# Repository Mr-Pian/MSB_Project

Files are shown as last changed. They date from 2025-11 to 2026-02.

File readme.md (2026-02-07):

# 2025 盟升杯电子设计竞赛 - G题：具有自动瞄准跟踪功能的激光通信系统





## 📖 项目简介 (Introduction)

本项目为 **2025 盟升杯电子设计竞赛** **[G题]** 的参赛工程源码及硬件方案，同时该设计采用了创新的**共轴光路**设计方案，从而达到更高精度的瞄准。
我们设计了一套**激光自动瞄准与跟踪通信系统**，系统分为发射端（TX）和接收端（RX），能够实现快速的目标搜索、锁定以及稳定的激光数据传输。

### 🎥 视频演示
我在 Bilibili 上录制了关于共轴光路的详细介绍和演示视频，欢迎观看！

👉 **[点击观看 B站视频演示](https://www.bilibili.com/video/BV11VFkzCEsm/?vd_source=f163b375ae59addf986a6a39b1f11695)**

---

## 📂 仓库目录结构 (Repository Structure)

本仓库包含了从硬件设计、嵌入式软件到机械结构的全部资料：

```text
MSB_Project/
├── 3D/                     # 机械结构文件
│   └── 云台3D.step         # 二维云台的3D建模文件
├── Document/               # 比赛相关文档
│   ├── G题...pdf           # 官方赛题说明
│   ├── SCH_...pdf          # 硬件weAct扩展板原理图 PDF 导出
│   └── MSB_parameters.txt  # 系统
├── firmware/               # 嵌入式控制源码
│   ├── MSB/                # [发射端主控] 基于 STM32H750VBT6（WeAct核心板）
│   │   ├── Control/        # 闭环控制算法 (PID, 云台控制)
│   │   ├── YunTai/         # 云台电机驱动逻辑
│   │   └── ...
│   ├── MSB_RX/             # [接收机主控] 基于 STM32F103C8T6
│   │   ├── Core/Src/oled.c # OLED 显示驱动
│   │   └── ...
│   └── laserrx/            # [激光接收器主控] 基于 STM32G031
├── hardware/               # 硬件工程文件
│   └── ms/                 # KiCad PCB 工程 (原理图与PCB源文件)
├── software/               # 上位机与仿真脚本
│   ├── smp/                # 树莓派视觉python脚本
│   └── naickp/             # 串口屏/UI 相关工程文件
└── README.md
```
## 🛠️ 硬件方案 (Hardware)

系统采用多MCU协同工作的架构：

| 模块 | 核心芯片 | 主要功能 |
| :--- | :--- | :--- |
| **发射端主控** | **STM32H750VBT6** | 负责云台姿态控制 (PID)、激光调制 |
| **视觉识别** | **Rpi5** | 负责图像识别 |
| **接收器主控** | **STM32G031** | 负责解调信号、显示通信数据 |
| **接收机旋转调速主控** | **STM32F103C8T6** | 负责接收机转速设置 |
| **PCB设计** | **KiCad** | 开源EDA工具设计的双层/四层板 |
| **显示交互** | ST7735 / OLED | 实时显示系统状态与接收文字 |

## 💻 软件与算法 (Software & Algorithms)

### 1. 嵌入式控制 (Firmware)
- **控制算法**：在 `firmware/MSB/Control` 中实现了增量式 **PID算法**，用于二维云台的高精度闭环控制。
- **驱动开发**：包含步进电机/舵机驱动 (`DMR4315`)、激光调制驱动等。
- **开发环境**：STM32CubeMX + Keil / CMake。

### 2. 视觉识别 (CV)
- 在 `software/smp` 目录下提供了在树莓派5上运行的 **Python** 脚本。
- 实现了 **卡尔曼滤波 (Kalman Filter)** 的规矩验证 (`kalman_filter_module.py`)，用于预测目标轨迹，提高动态跟踪的鲁棒性。

## 🚀 使用说明 (Usage)

1.  **硬件制作**：
    - 参考 `hardware/ms` 下的 Gerber 文件或 KiCad 工程进行 PCB 打样与焊接。
    - 参考 `3D/` 目录打印机械结构件并组装。
2.  **固件烧录**：
    - 使用 ST-Link/Dap-Link 分别下载 `firmware` 目录下对应的 H750、F103 和 G031 固件。
3.  **系统联调**：
    - 上电后，发射端将自动运行自检并进入任务模式

## 🤝 贡献 (Contributing)

本项目由以下团队成员共同完成：

- **@Mr-Pian** - 队长 / 电控 / 机械
- **@PickaxeHit** - 接收器全栈 / 模拟部分设计
- **@nailong-xpy** - 视觉算法 / 接收机软件 / 串口屏

  <table>
  <tr>
    <td align="center">
      <a href="https://github.com/Mr-Pian">
        Mr-Pian
        <br />
        <sub><b>Mr-Pian</b></sub>
      </a>
    </td>
    <td align="center">
      <a href="https://github.com/PickaxeHit">
        PickaxeHit
        <br />
        <sub><b>PickaxeHit</b></sub>
      </a>
    </td>
    <td align="center">
      <a href="https://github.com/nailong-xpy">
        nailong-xpy
        <br />
        <sub><b>nailong-xpy</b></sub>
      </a>
    </td>
  </tr>
</table>

如果你对本项目感兴趣，欢迎 Fork 和 Star！有问题请在 Issue 中提出。

---
*Created by Mr-Pian*

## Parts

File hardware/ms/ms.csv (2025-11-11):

Reference | Qty | Value | DNP | Exclude from BOM | Exclude from Board | Footprint | Datasheet
C1,C2,C4,C5 | 4 | 33p |  |  |  | Capacitor_SMD:C_0603_1608Metric | ~
C3,C6,C9,C10,C11,C12,C14,C16,C20,C22,C27 | 11 | 100n |  |  |  | Capacitor_SMD:C_0603_1608Metric | ~
C7,C8,C13,C15,C25,C26 | 6 | 10u |  |  |  | Capacitor_SMD:C_0603_1608Metric | ~
C17,C18 | 2 | 1u |  |  |  | Capacitor_SMD:C_0603_1608Metric | ~
C19,C21,C24 | 3 | 4u7 |  |  |  | Capacitor_SMD:C_0603_1608Metric | ~
C23 | 1 | 2u2 |  |  |  | Capacitor_SMD:C_0603_1608Metric | ~
D1,D2,D3,D4,D5,D6,D7,D8,D9,D10,D11,D12,D13,D14,D15,D16,D17,D18,D19,D20,D21,D22,D23,D24,D25,D26,D27,D28,D29,D30,D31,D32,D33,D34,D35,D36 | 36 | LED |  |  |  | LED_THT:LED_D5.0mm_Clear | ~
D37,D38,D39,D40 | 4 | 3v3 |  |  |  | Diode_SMD:D_SOD-123 | ~
D41 | 1 | LED |  |  |  | LED_SMD:LED_0805_2012Metric | ~
DS1 | 1 | OLED-128O032D |  |  |  | Library:OLED-128O032D
H1,H2,H3,H4 | 4 | MountingHole_Pad |  | 从 BOM 中移除 |  | MountingHole:MountingHole_3.2mm_M3_Pad | ~
J1 | 1 | DBG |  |  |  | Connector_PinHeader_2.54mm:PinHeader_1x08_P2.54mm_Vertical | ~
J2 | 1 | BAT |  |  |  | Connector_JST:JST_XH_B2B-XH-A_1x02_P2.50mm_Vertical | ~
J3 | 1 | USB_C_Receptacle_PowerOnly_6P |  |  |  | Connector_USB:USB_C_Receptacle_GCT_USB4125-xx-x_6P_TopMnt_Horizontal | https://www.usb.org/sites/default/files/documents/usb_type-c.zip
R1,R5,R8,R11 | 4 | 470k |  |  |  | Resistor_SMD:R_0603_1608Metric | ~
R2,R4,R7,R10 | 4 | 0 |  |  |  | Resistor_SMD:R_0603_1608Metric | ~
R3,R6,R9,R12 | 4 | 1k |  |  |  | Resistor_SMD:R_0603_1608Metric | ~
R13,R14,R15,R16,R17,R18,R20 | 7 | 100k |  |  |  | Resistor_SMD:R_0603_1608Metric | ~
R19 | 1 | NC | DNP (不作装配) |  |  | Resistor_SMD:R_0603_1608Metric | ~
R21,R22 | 2 | 1M |  |  |  | Resistor_SMD:R_0603_1608Metric | ~
R23,R24,R25,R33,R34 | 5 | 10k |  |  |  | Resistor_SMD:R_0603_1608Metric | ~
R26 | 1 | 560k |  |  |  | Resistor_SMD:R_0603_1608Metric | ~
R27,R28,R29 | 3 | 4k7 |  |  |  | Resistor_SMD:R_0603_1608Metric | ~
R30,R31,R32 | 3 | 5k1 |  |  |  | Resistor_SMD:R_0603_1608Metric | ~
RV1,RV2,RV3,RV4 | 4 | 2k |  |  |  | Potentiometer_SMD:Potentiometer_Bourns_TC33X_Vertical | ~
SW1 | 1 | BUTTON |  |  |  | Button_Switch_SMD:SW_Push_1P1T_NO_Vertical_Wuerth_434133025816 | ~
SW2 | 1 | RESET |  |  |  | Button_Switch_SMD:SW_Push_1P1T_NO_Vertical_Wuerth_434133025816 | ~
U1 | 1 | TLV75733PDBV |  |  |  | Package_TO_SOT_SMD:SOT-23-5 | https://www.ti.com/lit/ds/symlink/tlv757p.pdf
U2 | 1 | STM32G031G8Ux |  |  |  | Package_DFN_QFN:QFN-28_4x4mm_P0.5mm | https://www.st.com/resource/en/datasheet/stm32g031g8.pdf
U3 | 1 | OP_T |  |  |  | Package_SO:SOIC-8_3.9x4.9mm_P1.27mm | ~
U4 | 1 | OP_B |  |  |  | Package_SO:SOIC-8_3.9x4.9mm_P1.27mm | ~
U5 | 1 | Opamp_Dual |  |  |  | Package_SO:SOIC-8_3.9x4.9mm_P1.27mm | ~
U6 | 1 | TP4056-42-ESOP8 |  |  |  | Package_SO:SOIC-8-1EP_3.9x4.9mm_P1.27mm_EP2.41x3.3mm | https://www.lcsc.com/datasheet/lcsc_datasheet_2410121619_TOPPOWER-Nanjing-Extension-Microelectronics-TP4056-42-ESOP8_C16581.pdf

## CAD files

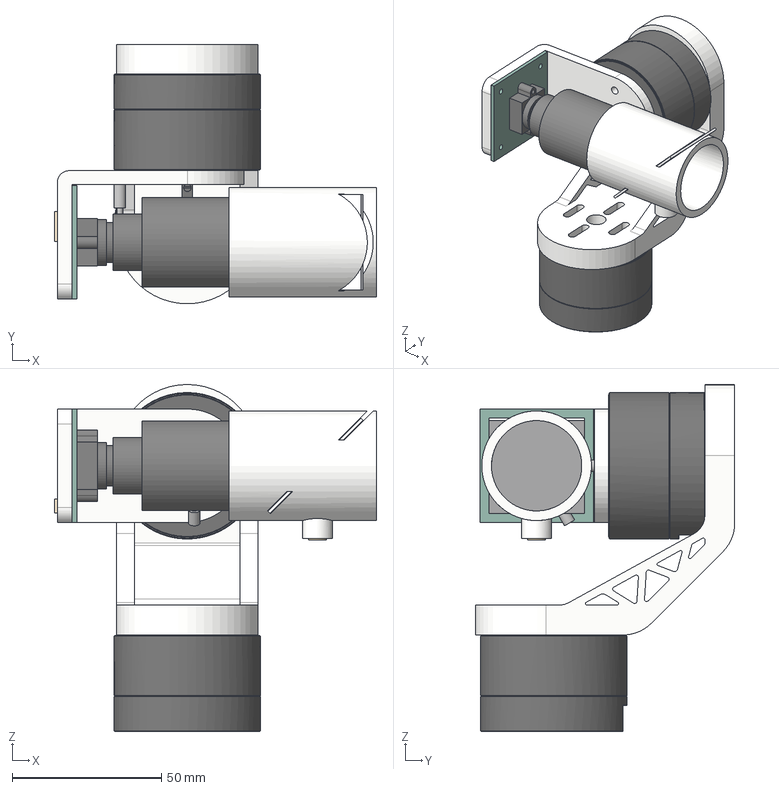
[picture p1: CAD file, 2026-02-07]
3D/云台3D.step
107.9 x 86.8 x 116.1 mm
L4315-¶¨×Ó
6702Öá³Ð x 2
L4315-×ª×Ó
L4315-ÌúÈ¦
L4315Çý¶¯°å
L4315±àÂëÆ÷´Å×ù
9.5-5-3±àÂëÆ÷´Å¸Ö
L4315-ºó¸Ç°å
L4315-¶¨×Ó_1
6702Öá³Ð_1 x 2
L4315-×ª×Ó_1
L4315-ÌúÈ¦_1
L4315Çý¶¯°å_1
L4315±àÂëÆ÷´Å×ù _1
9.5-5-3±àÂëÆ÷´Å¸Ö _1
L4315-ºó¸Ç°å_1
二维云台支架
50mm焦距摄像头
5/5分光镜
分光镜头罩
小号405nm激光笔
摄像头后飘支架

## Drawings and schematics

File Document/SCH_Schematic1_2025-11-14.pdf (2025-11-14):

# 蜂鸣器

电源

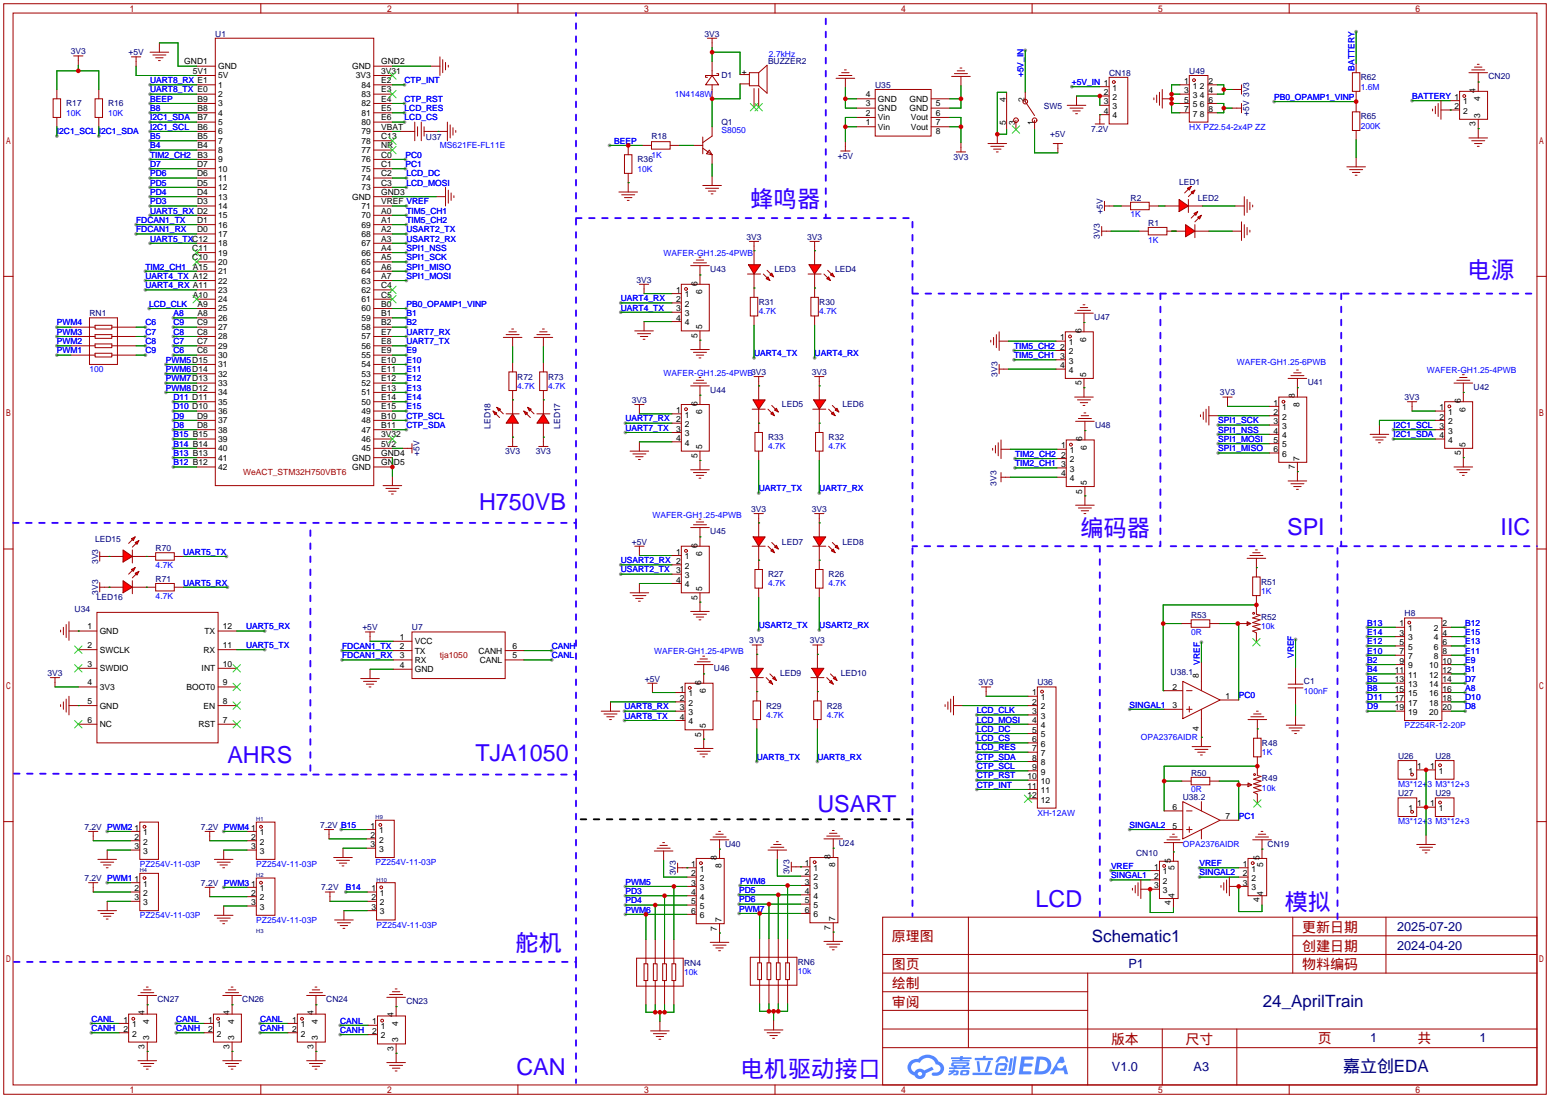
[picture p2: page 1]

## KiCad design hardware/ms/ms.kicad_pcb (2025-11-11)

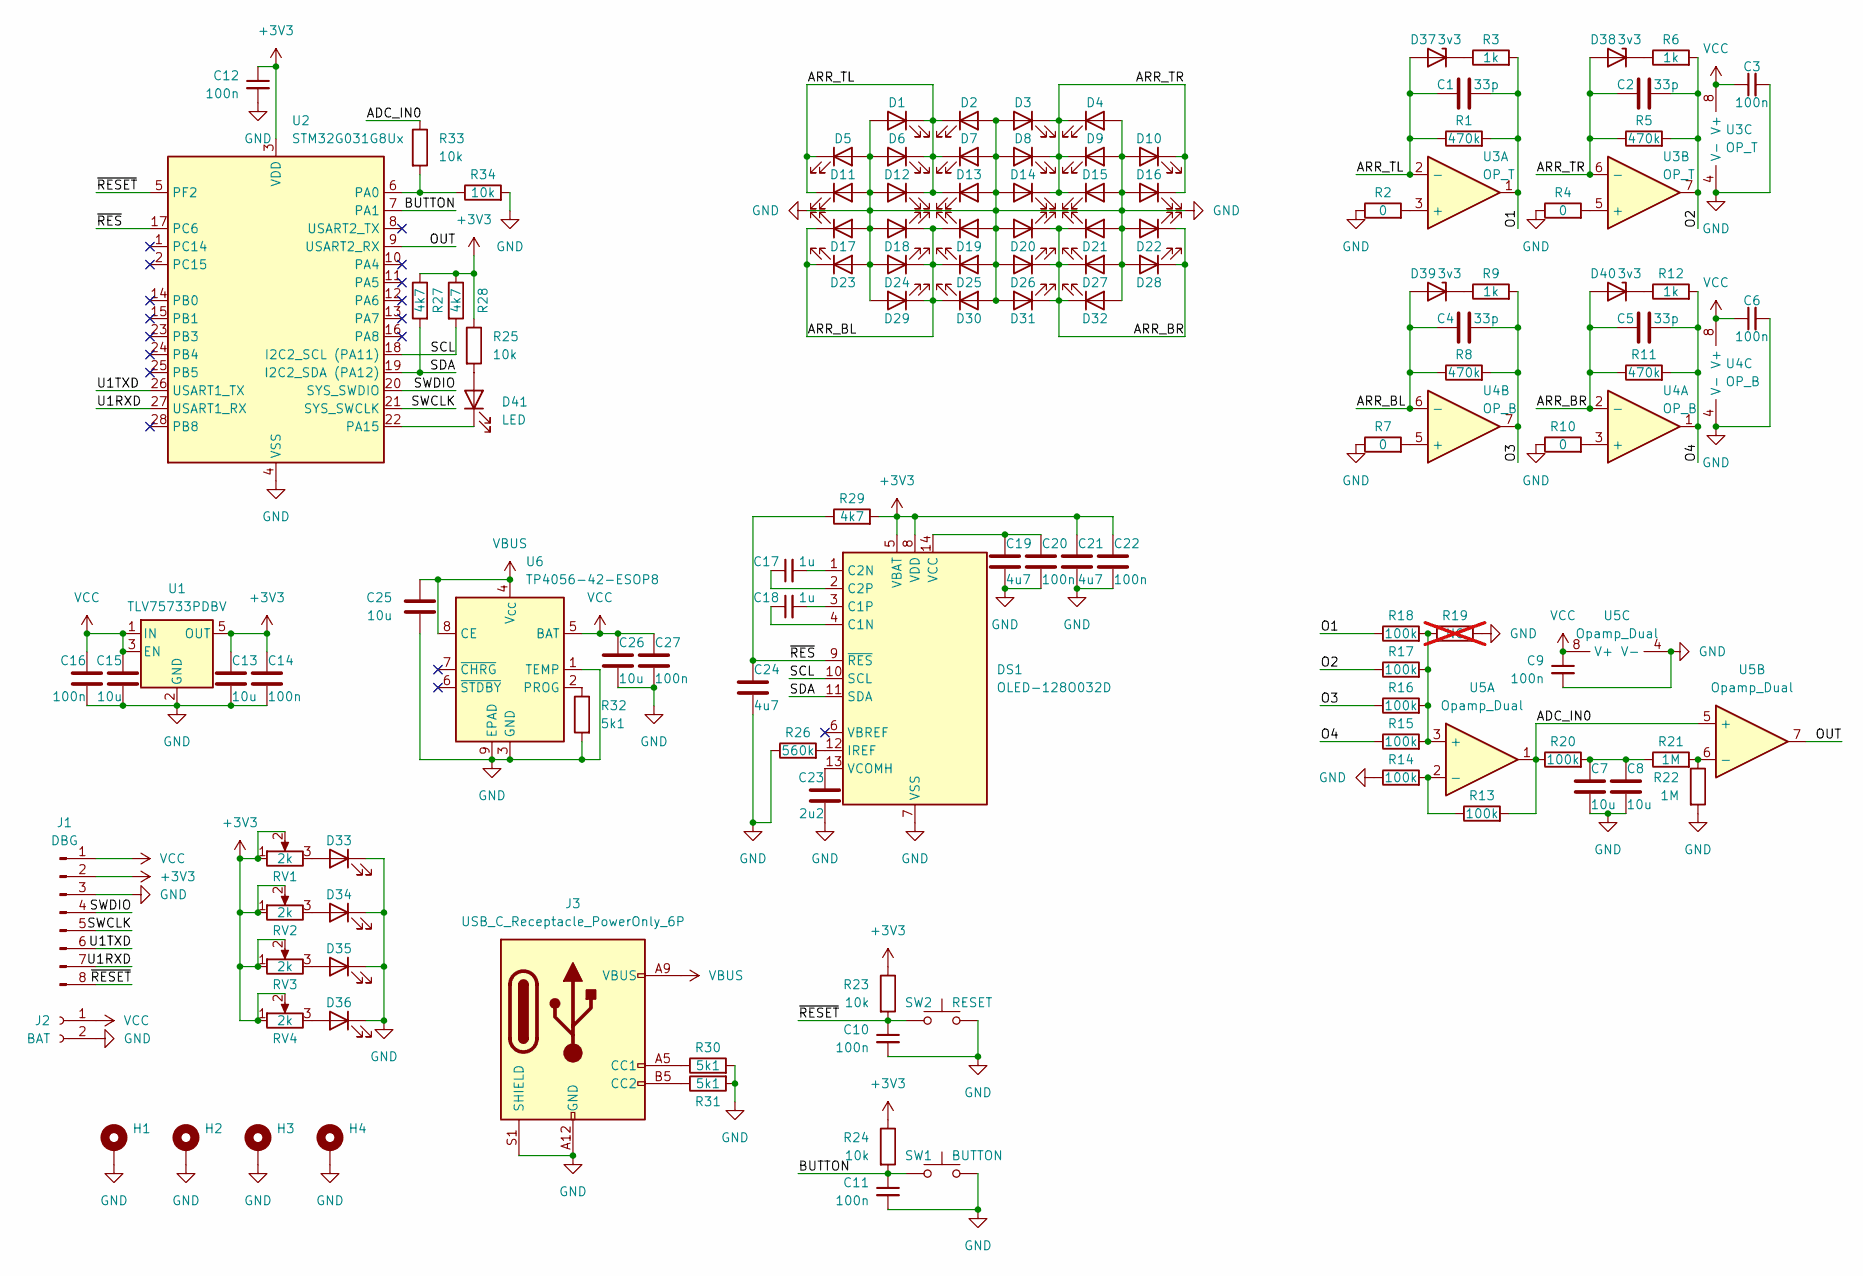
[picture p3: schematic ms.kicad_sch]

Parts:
C1, C2, C4, C5: 33p; C_0603_1608Metric
C3, C6, C9, C10, C11, C12, C14, C16, C20, C22, C27: 100n; C_0603_1608Metric
C7, C8, C13, C15, C25, C26: 10u; C_0603_1608Metric
C17, C18: 1u; C_0603_1608Metric
C19, C21, C24: 4u7; C_0603_1608Metric
C23: 2u2; C_0603_1608Metric
D1, D2, D3, D4, D5, D6, D7, D8, D9, D10, D11, D12, D13, D14, D15, D16, D17, D18, D19, D20, D21, D22, D23, D24, D25, D26, D27, D28, D29, D30, D31, D32, D33, D34, D35, D36: LED; LED_D5.0mm_Clear
D37, D38, D39, D40: 3v3; D_SOD-123
D41: LED; LED_0805_2012Metric
DS1: OLED-128O032D
H1, H2, H3, H4: MountingHole_Pad; MountingHole_3.2mm_M3_Pad
J1: DBG; PinHeader_1x08_P2.54mm_Vertical
J2: BAT; JST_XH_B2B-XH-A_1x02_P2.50mm_Vertical
J3: USB_C_Receptacle_PowerOnly_6P; USB_C_Receptacle_GCT_USB4125-xx-x_6P_TopMnt_Horizontal
R1, R5, R8, R11: 470k; R_0603_1608Metric
R2, R4, R7, R10: 0; R_0603_1608Metric
R3, R6, R9, R12: 1k; R_0603_1608Metric
R13, R14, R15, R16, R17, R18, R20: 100k; R_0603_1608Metric
R19: NC; R_0603_1608Metric; not fitted
R21, R22: 1M; R_0603_1608Metric
R23, R24, R25, R33, R34: 10k; R_0603_1608Metric
R26: 560k; R_0603_1608Metric
R27, R28, R29: 4k7; R_0603_1608Metric
R30, R31, R32: 5k1; R_0603_1608Metric
RV1, RV2, RV3, RV4: 2k; Potentiometer_Bourns_TC33X_Vertical
SW1: BUTTON; SW_Push_1P1T_NO_Vertical_Wuerth_434133025816
SW2: RESET; SW_Push_1P1T_NO_Vertical_Wuerth_434133025816
U1: TLV75733PDBV; SOT-23-5
U2: STM32G031G8Ux; QFN-28_4x4mm_P0.5mm
U3: OP_T; SOIC-8_3.9x4.9mm_P1.27mm
U4: OP_B; SOIC-8_3.9x4.9mm_P1.27mm
U5: Opamp_Dual; SOIC-8_3.9x4.9mm_P1.27mm
U6: TP4056-42-ESOP8; SOIC-8-1EP_3.9x4.9mm_P1.27mm_EP2.41x3.3mm

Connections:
+3V3: C12.1, C13.1, C14.1, C21.1, C22.1, DS1.5 (VBAT), DS1.8 (VDD), J1.2, R23.1, R24.1, R25.1, R27.1, R28.1, R29.2, RV1.1, RV1.2, RV2.1, RV2.2, RV3.1, RV3.2, RV4.1, RV4.2, U1.5 (OUT), U2.3 (VDD)
/ADC_IN0: R13.2, R20.1, R33.1, U5.1, U5.5 (+)
/ARR_BL: C4.1, D17.1 (K), D18.1 (K), D19.1 (K), D23.1 (K), D24.1 (K), D25.1 (K), D29.1 (K), D30.1 (K), D39.2 (A), R8.1, U4.6 (-)
/ARR_BR: C5.1, D20.1 (K), D21.1 (K), D22.1 (K), D26.1 (K), D27.1 (K), D28.1 (K), D31.1 (K), D32.1 (K), D40.2 (A), R11.1, U4.2 (-)
/ARR_TL: C1.1, D1.1 (K), D2.1 (K), D5.1 (K), D6.1 (K), D7.1 (K), D11.1 (K), D12.1 (K), D13.1 (K), D37.2 (A), R1.1, U3.2 (-)
/ARR_TR: C2.1, D3.1 (K), D4.1 (K), D8.1 (K), D9.1 (K), D10.1 (K), D14.1 (K), D15.1 (K), D16.1 (K), D38.2 (A), R5.1, U3.6 (-)
/BUTTON: C11.1, R24.2, SW1.1, U2.7 (PA1)
/O1: C1.2, R1.2, R3.2, R18.1, U3.1
/O2: C2.2, R5.2, R6.2, R17.1, U3.7
/O3: C4.2, R8.2, R9.2, R16.1, U4.7
/O4: C5.2, R11.2, R12.2, R15.1, U4.1
/OUT: U2.9 (USART2_RX), U5.7
/SCL: DS1.10 (SCL), R28.2, U2.18 (I2C2_SCL (PA11))
/SDA: DS1.11 (SDA), R27.2, U2.19 (I2C2_SDA (PA12))
/SWCLK: J1.5, U2.21 (SYS_SWCLK)
/SWDIO: J1.4, U2.20 (SYS_SWDIO)
/U1RXD: J1.7, U2.27 (USART1_RX)
/U1TXD: J1.6, U2.26 (USART1_TX)
/~RESET: C10.1, J1.8, R23.2, SW2.1, U2.5 (PF2)
/~RES: C24.1, DS1.9 (~RES), R29.1, U2.17 (PC6)
GND: C3.2, C6.2, C7.2, C8.2, C9.2, C10.2, C11.2, C12.2, C13.2, C14.2, C15.2, C16.2, C19.2, C20.2, C21.2, C22.2, C23.2, C24.2, C25.2, C26.2, C27.2, D1.2 (A), D2.2 (A), D3.2 (A), D4.2 (A), D5.2 (A), D6.2 (A), D7.2 (A), D8.2 (A), D9.2 (A), D10.2 (A), D11.2 (A), D12.2 (A), D13.2 (A), D14.2 (A), D15.2 (A), D16.2 (A), D17.2 (A), D18.2 (A), D19.2 (A), D20.2 (A), D21.2 (A), D22.2 (A), D23.2 (A), D24.2 (A), D25.2 (A), D26.2 (A), D27.2 (A), D28.2 (A), D29.2 (A), D30.2 (A), D31.2 (A), D32.2 (A), D33.1 (K), D34.1 (K), D35.1 (K), D36.1 (K), DS1.7 (VSS), H1.1, H2.1, H3.1, H4.1, J1.3, J2.2, J3.A12 (GND), J3.B12 (GND), J3.S1 (SHIELD), R2.1, R4.1, R7.1, R10.1, R14.1, R19.2, R22.2, R26.1, R30.2, R31.2, R32.2, R34.2, SW1.2, SW2.2, U1.2 (GND), U2.4 (VSS), U3.4 (V-), U4.4 (V-), U5.4 (V-), U6.1 (TEMP), U6.3 (GND), U6.9 (EPAD)
unnamed: C7.1, C8.1, R20.2, R21.1
unnamed: D33.2 (A), RV1.3
unnamed: D34.2 (A), RV2.3
unnamed: D35.2 (A), RV3.3
unnamed: D36.2 (A), RV4.3
unnamed: D37.1 (K), R3.1
unnamed: D38.1 (K), R6.1
unnamed: D39.1 (K), R9.1
unnamed: D40.1 (K), R12.1
unnamed: D41.2 (A), R25.2
unnamed: D41.1 (K), U2.22 (PA15)
unnamed: C18.1, DS1.4 (C1N)
unnamed: C18.2, DS1.3 (C1P)
unnamed: C17.2, DS1.1 (C2N)
unnamed: C17.1, DS1.2 (C2P)
unnamed: DS1.12 (IREF), R26.2
unnamed: C19.1, C20.1, DS1.14 (VCC)
unnamed: C23.1, DS1.13 (VCOMH)
unnamed: J3.A5 (CC1), R30.1
unnamed: J3.B5 (CC2), R31.1
unnamed: R33.2, R34.1, U2.6 (PA0)
unnamed: R2.2, U3.3 (+)
unnamed: R4.2, U3.5 (+)
unnamed: R10.2, U4.3 (+)
unnamed: R7.2, U4.5 (+)
unnamed: R15.2, R16.2, R17.2, R18.2, R19.1, U5.3 (+)
unnamed: R13.1, R14.2, U5.2 (-)
unnamed: R21.2, R22.1, U5.6 (-)
unnamed: R32.1, U6.2 (PROG)
VBUS: C25.1, J3.A9 (VBUS), J3.B9 (VBUS), U6.4 (V_{CC}), U6.8 (CE)
VCC: C3.1, C6.1, C9.1, C15.1, C16.1, C26.1, C27.1, J1.1, J2.1, U1.1 (IN), U1.3 (EN), U3.8 (V+), U4.8 (V+), U5.8 (V+), U6.5 (BAT)

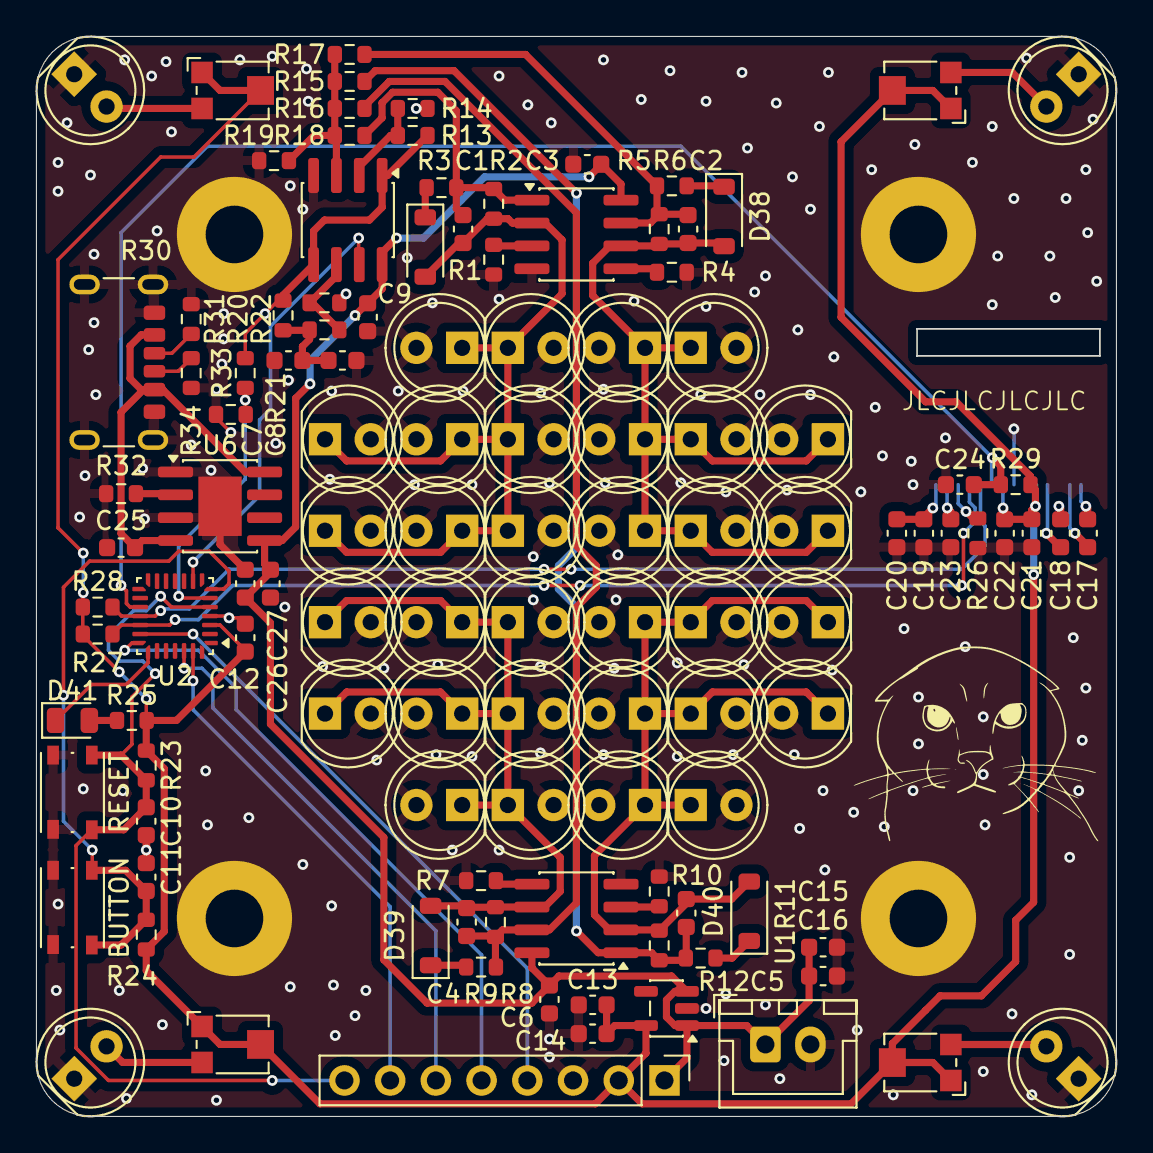
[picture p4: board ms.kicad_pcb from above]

Board: 2 copper layers, 60.0 x 60.0 mm, 122 parts (1 on the bottom side), 52 nets.

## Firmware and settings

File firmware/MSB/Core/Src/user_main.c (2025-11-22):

//
// Created by pickaxehit on 2025/11/11.
//

#include "delay/delay.h"
#include "yuntai.h"
#include "control.h"
#include "HCI.h"
#include "TFT18_ST7735S.h"
#include "DMR4315.h"
#include "laser_control.h"
#include "tim.h"
#include "usart.h"

/************基本参数配置************/
#define TASK1_ERROR 20
/************基本参数配置************/

/************必要变量定义************/
uint8_t fifo_data[100] = {0};//树莓派串口接受缓冲区
/************必要变量定义************/

/************必要标志定义************/
int swap_uart_buffer_counter = -50;
/************必要标志定义************/

int user_main(void)
{
    laser_set_level(0); //turn off the laser after init
    TFTSPI_Init();
    TFT_Printf(0, 0, COLOR_WHITE,COLOR_BLACK, fsize_8X16, "%5s", "FatFs Init:");
    TFT_Printf(0, 16, COLOR_WHITE,COLOR_BLACK, fsize_6X8, "%5s", "wait 1 sec");
    HCI_init();//人机交互初始化 (这里有读sd卡的1s延时)
    Control_Init();//控制初始化 (一定要放在HCI_init后面)
    HAL_UART_Receive_DMA(&huart7, fifo_data, 12);
    __HAL_UART_ENABLE_IT(&huart2, UART_IT_IDLE);
    HAL_UART_Receive_DMA(&huart2, buffer_from_screen, 100);
    HAL_TIM_Base_Start_IT(&htim14);//中低优先级定时器 5ms
    HAL_TIM_Base_Start_IT(&htim16);//高优先级定时器 1ms
    HAL_TIM_Base_Start_IT(&htim15);//中优先级定时器 2ms
    HAL_TIM_Base_Start_IT(&htim17);//低优先级定时器 100ms

    for (;;) {
        if (Fatfs_save_flag)//Fatfs保存
        {
            Fatfs_save_flag = 0;
            Write_SD_data(&MSB_Data);
        }
        if (pid_start_flag) {//Pid开始
            pid_start_flag = 0;
            pid_control_flag = 1;
            yuntai_set_zero_point();
            yuntai_set_flag(PID_CONTROL_FLAG);
        }
        if (set_zero_point_flag) {//云台调零点
            set_zero_point_flag = 0;
            yuntai_set_zero_point();
            delay_ms(10);
            motor_set_related_position(MOTOR_PITCH, 0);
            delay_ms(10);
            motor_set_related_position(MOTOR_YAW, 0);
        }
        switch (quest_num) {
            case -1:
                {
                    //do nothing
                    break;
                }
            case 1:
                {
                    //基础第一问
                    delay_ms(500);
                    laser_set_level(1);
                    quest_num = -1; //quit
                    break;
                }
            case 2:
                {
                    //基础第二问
                    HAL_Delay(10);
                    laser_transmit_data(laser_buffer, 6);//激光发送
                    break;
                }
            case 3:
                {
                    //基础第三问
                    HAL_Delay(10);
                    if (swap_uart_buffer_counter == 0) {
                        for (int j = 0; j < 5; j++) {
                            laser_buffer[j] = laser_temp_buffer2[j];
                        }
                    }
                    else if (swap_uart_buffer_counter == 50) {
                        for (int j = 0; j < 5; j++) {
                            laser_buffer[j] = laser_temp_buffer1[j];
                        }
                        swap_uart_buffer_counter = -50;
                    }
                    swap_uart_buffer_counter++;
                    laser_transmit_data(laser_buffer, 6);//激光发送
                    break;
                }
            case 4:
                {
                    yuntai_flags_control_enable_none_debug_mode = 0;
                    pid_control_flag = 1;
                    delay_ms(5);
                    motor_set_position_angle(MOTOR_YAW, yun_tai_init_angle[0]);
                    delay_ms(20);
                    motor_set_position_angle(MOTOR_PITCH, yun_tai_init_angle[1]);
                    delay_ms(400); //等待电机转到位置
                    yuntai_set_zero_point();
                    yuntai_flags_control_enable_none_debug_mode = 1;
                    yuntai_set_flag(PID_CONTROL_FLAG);
                    while (quest_num) {
                        HAL_Delay(10);
                        laser_transmit_data(laser_buffer, 6);//激光发送
                    }
                    break;
                }
            case 5:
                {
                    yuntai_flags_control_enable_none_debug_mode = 0;
                    pid_control_flag = 1;
                    delay_ms(5);
                    motor_set_position_angle(MOTOR_YAW, yun_tai_init_angle[0]);
                    delay_ms(20);
                    motor_set_position_angle(MOTOR_PITCH, yun_tai_init_angle[1]);
                    delay_ms(400); //等待电机转到位置
                    yuntai_set_zero_point();
                    yuntai_flags_control_enable_none_debug_mode = 1;
                    yuntai_set_flag(PID_CONTROL_FLAG);
                    while (quest_num) {
                        HAL_Delay(10);
                        if (swap_uart_buffer_counter == 0) {
                            for (int j = 0; j < 5; j++) {
                                laser_buffer[j] = laser_temp_buffer2[j];
                            }
                        }
                        else if (swap_uart_buffer_counter == 50) {
                            for (int j = 0; j < 5; j++) {
                                laser_buffer[j] = laser_temp_buffer1[j];
                            }
                            swap_uart_buffer_counter = -50;
                        }
                        swap_uart_buffer_counter++;
                        laser_transmit_data(laser_buffer, 6);//激光发送
                    }
                    break;
                }
            case 6:
                {
                    HAL_Delay(10);
                    laser_transmit_data(laser_buffer_for_task6, 3);//激光发送
                    break;
                }

            default:
                {
                    //quest_num 为0 停止位，只运行一次
                    quest_num = -1;//重新把flag置回空闲位
                    pid_stop_flag = 1;
                    swap_uart_buffer_counter = -50;
                    task6_first_code_received = 0; //创新点flag重置
                    yuntai_flags_control_enable_none_debug_mode = 1;
                    laser_buffer[1] = 'V';
                    laser_buffer[2] = 'O';
                    laser_buffer[3] = 'I';
                    laser_buffer[4] = 'D';
                    laser_set_level(0);
                    break;
                }
        }
        if (pid_stop_flag) {
            pid_stop_flag = 0;
            pid_control_flag = 0;

            the_yun_tai.Pitch_pid->output = 0.0f;
            the_yun_tai.Yaw_pid->output = 0.0f;
            yuntai_set_flag(STABLE_CONTROL_FLAG);
        }
    }
    return 0;
}

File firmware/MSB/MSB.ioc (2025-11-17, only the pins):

Mcu.UserName=STM32H750VBTx
PA1.Signal=UART4_RX
PA12.Signal=UART4_TX
PA2.Signal=USART2_TX
PA3.Signal=USART2_RX
PC10.Signal=SDMMC1_D2
PC11.Signal=SDMMC1_D3
PC12.Signal=SDMMC1_CK
PC13.GPIO_Label=K1
PC13.Signal=GPIO_Input
PC8.Signal=SDMMC1_D0
PC9.Signal=SDMMC1_D1
PD2.Signal=SDMMC1_CMD
PE0.Signal=UART8_RX
PE1.Signal=UART8_TX
PE10.GPIO_Label=LCD_BLK
PE10.Signal=GPIO_Output
PE11.GPIO_Label=LCD_CS
PE11.Signal=GPIO_Output
PE12.Signal=SPI4_SCK
PE13.GPIO_Label=LCD_WR_RS
PE13.Signal=GPIO_Output
PE14.Signal=SPI4_MOSI
PE3.Signal=GPIO_Output
PE7.Signal=UART7_RX
PE8.Signal=UART7_TX

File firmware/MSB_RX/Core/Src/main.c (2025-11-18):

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
/* Includes ------------------------------------------------------------------*/
#include "main.h"
#include "i2c.h"
#include "tim.h"
#include "usart.h"
#include "gpio.h"

/* USER CODE BEGIN Includes */
#include <stdio.h>

#include "oled.h"
#include "font.h"
#include <string.h>
#include "ssd1306.h"
/* USER CODE END Includes */


/* USER CODE BEGIN PV */
int Value = 10;
char text[10] = {0},ctrl[5]="Stop";
uint8_t up_flag=0,down_flag=0,ctrl_flag=0;

/* USER CODE END PV */

void SystemClock_Config(void);
/* USER CODE BEGIN PFP */
void Refresh_SSD1306(void) {
  ssd1306_clear(0);
  ssd1306_draw_string_12_24(0, 5, ctrl,1, 1 );
  sprintf(text, "%d.%d",Value/10,Value%10);
  ssd1306_draw_string_12_24(80,5,text,1,1);
  ssd1306_refresh();
  ssd1306_refresh();//主页
};
void ZDT_SetSpeed_Right(int speed) {
  // Placeholder for speed setting function
   char buf[8]={0x01,0xF6,0x00,0x00,0x00,0x00,0x00,0x6B};
   buf[4]=speed&0xFF;
   buf[5]=(speed>>8)&0xFF;
   HAL_UART_Transmit(&huart2, (uint8_t*)buf, 8, HAL_MAX_DELAY);
};
void ZDT_SetSpeed_Left(int speed) {
  char buf[8]={0x01,0xF6,0x01,0x00,0x00,0x00,0x00,0x6B};
  buf[4]=speed&0xFF;
  buf[5]=(speed>>8)&0xFF;
  HAL_UART_Transmit(&huart2, (uint8_t*)buf, 8, HAL_MAX_DELAY);
}
void ZDT_STOP(void) {
  char buf[5]={0x01, 0xFE ,0x98 ,0x00, 0x6B};
  HAL_UART_Transmit(&huart2, (uint8_t*)buf, 5, HAL_MAX_DELAY);
}
/* USER CODE END PFP */

/**
  * @brief  The application entry point.
  * @retval int
  */
int main(void)
{

  /* MCU Configuration--------------------------------------------------------*/

  /* Reset of all peripherals, Initializes the Flash interface and the Systick. */
  HAL_Init();

  /* Configure the system clock */
  SystemClock_Config();

  /* Initialize all configured peripherals */
  MX_GPIO_Init();
  MX_I2C1_Init();
  MX_TIM1_Init();
  MX_USART2_UART_Init();
  /* USER CODE BEGIN 2 */
  HAL_Delay(100);
  ssd1306_init();
  ssd1306_clear(0);
  ssd1306_draw_string_12_24(45, 5, "MSB",1, 1 );
  ssd1306_refresh();
  ssd1306_refresh();//标题
  while (1) {
    if (HAL_GPIO_ReadPin(CTRL_GPIO_Port, CTRL_Pin)==GPIO_PIN_RESET) break;
  }
  HAL_Delay(200);
  Refresh_SSD1306();


  HAL_TIM_Base_Start_IT(&htim1);

  /* USER CODE END 2 */

  /* Infinite loop */
  /* USER CODE BEGIN WHILE */
  while (1)
  {
    /* USER CODE END WHILE */

    /* USER CODE BEGIN 3 */
  }
  /* USER CODE END 3 */
}

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
/* USER CODE BEGIN 4 */
#define DELAY_LEN 2
void HAL_TIM_PeriodElapsedCallback(TIM_HandleTypeDef* htim) {
  if (htim->Instance == TIM1) {
    static int LorR=0,Uf=0,Df=0;
    static int Delay=DELAY_LEN,DDelay=DELAY_LEN;

    if (HAL_GPIO_ReadPin(CTRL_GPIO_Port, CTRL_Pin) == GPIO_PIN_RESET && ctrl_flag == 0) {
      ctrl_flag = 1;
      if (strcmp("Stop", ctrl) == 0) {
        if (LorR == 0) {
          strcpy(ctrl, "Right");
          Refresh_SSD1306();
          ZDT_SetSpeed_Right((int) ((float) Value * 19.0 / 10.0));
          LorR=1;
        }else {
          strcpy(ctrl, "Left");
          Refresh_SSD1306();
          ZDT_SetSpeed_Left((int) ((float) Value * 19.0 / 10.0));
          LorR=0;
        }
      }else {
        strcpy(ctrl, "Stop");
        Refresh_SSD1306();
        ZDT_STOP();
      }
    } else if (HAL_GPIO_ReadPin(CTRL_GPIO_Port, CTRL_Pin) == GPIO_PIN_SET) {
      ctrl_flag = 0;
    }
    //*******************************************************************************************//
    if (HAL_GPIO_ReadPin(UP_GPIO_Port, UP_Pin) == GPIO_PIN_RESET  && strcmp("Stop", ctrl) == 0) {
      if (Uf==0) {
        Uf=1;
        if (Value < 60) {
          Value+=1;
        }
      }else {
        Delay--;
        if (Delay <= 0) {
          Delay=DELAY_LEN;
          if (Value < 60) {
            Value+=1;
          }
        }
      }
      Refresh_SSD1306();
      return;
    } else if (HAL_GPIO_ReadPin(UP_GPIO_Port, UP_Pin) == GPIO_PIN_SET) {
      Delay=DELAY_LEN;
      Uf=0;
    }
    //*******************************************************************************************//
    if (HAL_GPIO_ReadPin(DOWN_GPIO_Port, DOWN_Pin) == GPIO_PIN_RESET  && strcmp("Stop", ctrl) == 0) {
      if (Df==0) {
        Df=1;
        if (Value >10) {
          Value-=1;
        }
      }else {
        DDelay--;
        if (DDelay <= 0) {
          DDelay=DELAY_LEN;
          if (Value >10) {
            Value-=1;
          }
        }
      }
      Refresh_SSD1306();
      return;
    } else if (HAL_GPIO_ReadPin(DOWN_GPIO_Port, DOWN_Pin) == GPIO_PIN_SET) {
      DDelay=DELAY_LEN;
      Df = 0;
    }


  }

}
/* USER CODE END 4 */
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


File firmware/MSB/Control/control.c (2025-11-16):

//
// Created by maodie on 2025/10/29.
//
#include "control.h"
#include "tim.h"
#include "DMR4315.h"
#include "HCI.h"
#include "usart.h"

// 初始化结构体
Yun_tai_typedef the_yun_tai;
PID_Controller_TypeDef yaw_pid_controller;
PID_Controller_TypeDef pitch_pid_controller;
Pixel_typedef real_pixel;
Pixel_typedef target_pixel;
Pixel_target_typedef the_pixel_target;
MSB_typedef the_msb;
uint16_convert_typedef convert_data;

void Control_Init(void) {
    yuntai_set_zero_point();
    // // 复位云台
    //yuntai_reset();
    // 云台设置零点

    // Pid 初始化 (包括设置从SD卡中读取的初始值)
    the_yun_tai.Yaw_pid = &yaw_pid_controller;
    the_yun_tai.Pitch_pid = &pitch_pid_controller;
    pid_init(the_yun_tai.Pitch_pid);
    the_yun_tai.Pitch_pid->f_param_init(the_yun_tai.Pitch_pid, PID_Speed, MSB_Data.Max_y_output,
                                        MSB_Data.Max_y_output, 0.0f, MSB_Data.pitch_kp, MSB_Data.pitch_ki,
                                        MSB_Data.pitch_kd);
    the_yun_tai.Pitch_pid->f_pid_switch(the_yun_tai.Pitch_pid, 1);//使能pid

    pid_init(the_yun_tai.Yaw_pid);
    the_yun_tai.Yaw_pid->f_param_init(the_yun_tai.Yaw_pid, PID_Speed, MSB_Data.Max_x_output,
                                      MSB_Data.Max_x_output, 0.0f, MSB_Data.yaw_kp, MSB_Data.yaw_ki, MSB_Data.yaw_kd);
    the_yun_tai.Yaw_pid->f_pid_switch(the_yun_tai.Yaw_pid, 1);//使能pid
    // 赋值
    the_pixel_target.real_pixel = &real_pixel;
    the_pixel_target.target_pixel = &target_pixel;
    the_msb.the_pixel_target = &the_pixel_target;

    the_msb.the_pixel_target->target_pixel->pixel_y = MSB_Data.pixel_y_target;
    the_msb.the_pixel_target->target_pixel->pixel_x = MSB_Data.pixel_x_target;
}

void get_xy_from_raspi(uint8_t *data, int fifo_length) {
    for (int i = 0; i < fifo_length; i++) {
        if (data[i] == 0x0a && data[i + 5] == 0x55)//找到帧
        {
            convert_data.raw_data[0] = data[i + 2];
            convert_data.raw_data[1] = data[i + 1];
            the_msb.the_pixel_target->real_pixel->pixel_x = convert_data.data;
            convert_data.raw_data[0] = data[i + 4];
            convert_data.raw_data[1] = data[i + 3];
            the_msb.the_pixel_target->real_pixel->pixel_y = convert_data.data;
        }
    }
}

void Laser_X_Control(void) {
    the_yun_tai.Yaw_pid->target = (float) the_msb.the_pixel_target->target_pixel->pixel_x;
    the_yun_tai.Yaw_pid->f_cal_pid(the_yun_tai.Yaw_pid,
                                   (float) the_msb.the_pixel_target->real_pixel->pixel_x);
    motor_set_position_angle(MOTOR_YAW, -the_yun_tai.Yaw_pid->output);
}

void Laser_Y_Control(void) {
    the_yun_tai.Pitch_pid->target = (float) the_msb.the_pixel_target->target_pixel->pixel_y;
    the_yun_tai.Pitch_pid->f_cal_pid(the_yun_tai.Pitch_pid,
                                     (float) the_msb.the_pixel_target->real_pixel->pixel_y);
    motor_set_position_angle(MOTOR_PITCH, -the_yun_tai.Pitch_pid->output);
}


//  send the info
void Laser_send(uint8_t *data, uint16_t length) {
    HAL_UART_Transmit_DMA(&huart4, data, length);
}

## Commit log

2025-10-28 0.0.1
    最初版本
2025-10-28 0.0.2
    完善了下项目结构，控制架构并未写完
2025-10-29 增加了smp工程文件夹以及部分代码
2025-10-29 init hardware
    [ms.kicad_pcb, ms.kicad_sch]
2025-10-29 0.1.0
    可以跟踪目标了，控制的大问题是5ms的控制周期太快导致两个电机不能都收到指令，现在是10ms然后电机自己的参数没有调整，导致移动很缓慢
2025-10-31 0.1.2
    对参数进行了调整，现在可以很快速的追踪光电，引入了HCI库，现在可以使用单按键简单控制模式
2025-11-01 0.1.3
    添加了题目
2025-11-03 0.1.4
    对set_zero_point 函数进行了修改，并修补了pid相对位置的小bug
2025-11-04 hardware update
    [ms.kicad_sch]
2025-11-06 software添加了串口屏，视觉新增kalman滤波
2025-11-08 hw update for new design
    [ms.kicad_sch]
2025-11-09 sch finished
    [ms.kicad_pcb, ms.kicad_sch]
2025-11-09 hw pcb init
    [ms.kicad_pcb, ms.kicad_sch]
2025-11-10 firmware SD卡完善
    1.更改了openocd 和 flash配置，完整的利用了h750 2m的flash
    2.挂载了Fatfs文件系统
    3.完成了从卡内读取参数，并保存的一系列接口
    4.HCI添加了闲置状态三击取消SD‘挂载（弹出卡）
2025-11-11 hw ver1
    [ms-B_Cu.gbr, ms-B_Mask.gbr, ms-B_Paste.gbr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]
2025-11-11 hw rev2
    [ms-B_Cu.gbr, ms-B_Mask.gbr, ms-B_Paste.gbr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]
2025-11-11 firmware与串口屏交互初步实现
    1.更换了LCD驱动库（爆改7735s方屏）
    2.使用串口空闲中断实现了和串口屏的通信
    3.设置瞄准点功能已经实现
2025-11-11 (almost)finished 1.1
    [ms.csv]
2025-11-13 串口屏添加键盘
2025-11-13 增加XpyEncoder
2025-11-14 smp增加固定修正点，串口屏修bug
2025-11-14 在document里添加了主控板原理图
2025-11-16 firmware task1,2完善和修复bug
    1.修复了控制时基的bug,把电机控制频率提高到了100hz
    2.完善了task2的发送，task2已经初步完成
    [DMR4315.c, HCI.c, MSB.ioc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]
2025-11-17 基础问完成，等待串口屏写ui，等待徐培原写接收机
2025-11-17 add laser rx proj
2025-11-18 fw add MSB_RX
    [dp.cfg]
2025-11-19 fw add Sd parameters
    [MSB_parameters.txt]
2025-11-21 fw finished task 4/5
    扩展基本完成，等待写创新
2025-11-22 fw finished task 6
    创新点实现已完成，固件部分基本定型
2025-11-23 上传了报告参考
2025-11-24 update laser rx proj
2025-11-24 报告0.2
    1. 报告1.1基本完成，还差接收机的激光通信方案
    2. 方案描述绘制完成
    3. 后续章节部分改了名，当然章节结构可能还有点问题
2025-11-26 画了一些框图
2025-11-26 报告0.3
    1. 基本上3.2节之前的内容全部完成（差2.4接收机理论推导 差3.1.1 3.1.2接收机电路设计）
    2. 在hardware里添加了现在使用的主板的JLCeda文件
2025-11-27 报告0.4
2025-11-27 报告1.0
    除了结论，其他的基本整完了，需要弄一下格式
2025-11-28 报告最终版
2025-11-28 完赛
    完赛鲁鲁鲁
2026-02-07 final
    上传了3D模型，移除了报告
    [云台3D.step]
2026-02-07 Stop tracking 报告
2026-02-07 Revise README for 2025 competition project details
    Updated the README to provide project details for the 2025 盟升杯电子设计竞赛, including project introduction, repository structure, hardware solutions, software algorithms, and contribution information.

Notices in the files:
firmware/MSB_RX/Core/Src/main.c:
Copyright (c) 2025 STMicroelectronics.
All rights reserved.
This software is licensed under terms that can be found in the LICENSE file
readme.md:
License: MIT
